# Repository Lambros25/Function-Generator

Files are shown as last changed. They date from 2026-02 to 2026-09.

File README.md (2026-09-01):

# AWG / DDS Function Generator

Laboratory-oriented DDS/AWG signal generator. Current build: v1.2, first revision to
reach full bring-up and characterisation.

## Specs

| | |
|---|---|
| Waveforms | Sine, Square, Sine+Noise, AM, FM |
| Sine range | 0Hz – 1MHz (characterised; DDS/phase-accumulator, <1mHz step) |
| Sine amplitude | ~16Vp-p max at 1kHz (analog pot) |
| Sine flatness | −0.07dB @ 100kHz, −3.1dB @ 1MHz at full drive; flat to −0.09dB @ 1MHz in low-current mode |
| Square range | to at least 2MHz |
| Square edges | ~20ns rise/fall, 10–90% at the BNC |
| Square duty | user-settable 1–99% (default 50%), TC4427-corrected to within ~12ns of target across 1kHz–2MHz |
| Noise | Gaussian-ish, SNR 0–60dB (nominal, not bench-calibrated) |
| AM / FM | depth 0–100% / deviation in Hz |
| Output | BNC, 50Ω series; measured source impedance 53Ω (sine) / 58Ω (square) at 1kHz, Hi-Z loads only |
| DC offset | none observed |
| Resolution | 8-bit R-2R ladder, ~7 effective bits (1% resistor matching) |
| Supply | USB and 2× 9V batteries (measured rails 9.52 / −9.54V) |
| Control | USB CDC serial (plain-text commands) + desktop UI (`scripts/awg_ui.py`) |
| MCU | Raspberry Pi Pico W (RP2040), 225MHz overclocked |

Full measured numbers and the outstanding measurement list: `docs/measurements.md`.
Known limitations and their causes: `docs/limitations.md`.

---

## Structure
- `logs/` — Detailed overview of every work session. (timestamped `.txt`)
- `docs/` — structured technical docs (Markdown)
- `hardware/` — schematics, PCB, BOM, simulations
- `firmware/` — RP2040/Pico firmware
- `scripts/` — helper scripts for committing/pushing logs
- `Push all.bat` / `Push Engineering logs.bat` — Batch files to make git pushing quick and easy.
- `images/` — Images of the project. Used for progress tracking.

### Documentation index (`docs/`)
Start with `design-philosophy.md`, then the version history in `version_requirements.md`,
then `v1_2_architecture.md`.

| File | Contents |
|---|---|
| `design-philosophy.md` | Why this exists and what is out of scope |
| `version_requirements.md` | Version history, requirements and their status |
| `v1_2_architecture.md` | Block diagram, board architecture, open questions |
| `Reconstruction.md` | The sine chain stage by stage, with values |
| `integrated-circuits.md` | Which ICs, in which stages, and why |
| `measurements.md` | Measured performance and what is still uncharacterised |
| `limitations.md` | Known limits, their causes, and mitigations |
| `lessons.md` | Mistakes, what they cost, and the rules derived from them |
| `fabrication.md` | JLCPCB process decisions, DRC, BOM and fee strategy |
| `firmware.md` | Pico W firmware |
| `future-work.md` | Deliberately deferred ideas |
| `overview.md` | Map of the documentation set |

---

## Tooling

- **EDA:** Altium Designer, custom library `lambros25` with LCSC part numbers stored at
  the symbol level so every placement inherits them.
- **Simulation:** LTspice. Behavioural ZOH plus noise source used to model the DAC
  output realistically.
- **Fabrication:** JLCPCB, Economic PCBA tier. Components from LCSC.
- **MCU:** Raspberry Pi Pico W.

Board is 70×70mm, 2-layer FR-4, all-SMD, with a single uninterrupted ground pour on the
bottom layer. Everything is machine-placed except the BNC and the Pico, which are
hand-soldered. `docs/fabrication.md` has the process detail.

---

# Versioning
Integers = major milestones with a defined goal. Decimals = fixes, optimizations, small
additions toward that goal.

| Version | Outcome |
|---|---|
| v0.x | Breadboard. Architecture validated; discrete square path abandoned above ~200kHz. |
| v1.0 | First PCB. Dead on arrival — BOM matcher substituted 2.21Ω for 2.21kΩ across the whole ladder. |
| v1.1 | All-SMD, LC Butterworth introduced. Dead on arrival — LM318 inputs merged onto one net during the KiCad→Altium migration. |
| v1.2 | Working. Current build, characterised. |

Two of three PCB revisions were lost to silent tool-transformation errors rather than
design errors. Both boards looked correct and passed every check that was not a physical
measurement. That is the through-line of this project so far.

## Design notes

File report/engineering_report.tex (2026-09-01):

% =====================================================================
%  AWG / DDS Function Generator — Engineering Process Report
%  Compile: pdflatex (x2, for cross-references and the ToC)
%  Requires: tcolorbox, cleveref, tikz — all standard in TeX Live full
% =====================================================================
\documentclass[11pt,a4paper]{article}

\usepackage[utf8]{inputenc}
\usepackage[T1]{fontenc}
\usepackage{lmodern}
\usepackage{textcomp}
\usepackage[margin=2.4cm]{geometry}
\usepackage{graphicx}
\usepackage{xcolor}
\usepackage{booktabs}
\usepackage{longtable}
\usepackage{array}
\usepackage{tabularx}
\usepackage{colortbl}
\usepackage{microtype}
\usepackage{pdflscape}
\usepackage{enumitem}
\usepackage{titlesec}
\usepackage{fancyhdr}
\usepackage{parskip}
\usepackage{float}
\usepackage{caption}
\usepackage{tikz}
\usepackage[most]{tcolorbox}

% ------------------------------------------------------------ colours
\definecolor{accent}{HTML}{2E4B3F}      % deep green — headings, links
\definecolor{accentline}{HTML}{9DB3A8}  % muted green — rules, ticks
\definecolor{accentpale}{HTML}{EDF2EF}  % wash — table headers, callouts
\definecolor{fail}{HTML}{8C2F1E}        % rust — failures, DOA markers
\definecolor{muted}{HTML}{5F5F5F}       % grey — source citations

% ------------------------------------------------------------ hyperref
\usepackage{hyperref}
\hypersetup{
  colorlinks=true,
  linkcolor=accent,
  citecolor=accent,
  urlcolor=accent,
  linktoc=all,
  bookmarksnumbered=true,
  bookmarksopen=true,
  pdftitle={AWG / DDS Function Generator — Engineering Process Report},
  pdfauthor={Lambros25},
  pdfsubject={Design, failure and bring-up of a laboratory-oriented DDS/AWG signal generator},
  pdfkeywords={AWG, DDS, function generator, R-2R, Butterworth, RP2040, Pico, PCB, Altium, JLCPCB}
}
\usepackage{bookmark}
\usepackage[capitalise,nameinlink]{cleveref}

% ------------------------------------------------------------ macros
\newcommand{\ohm}{\ensuremath{\Omega}}

% Repository links. Set \repobase to your public repo, or comment out the
% linked definitions below and uncomment the plain ones to disable linking.
\newcommand{\doc}[1]{\href{https://github.com/Lambros25/Function-Generator/blob/main/docs/#1}{\texttt{#1}}}
\newcommand{\docu}[2]{\href{https://github.com/Lambros25/Function-Generator/blob/main/docs/#1}{\texttt{#2}}}
\newcommand{\repofile}[1]{\href{https://github.com/Lambros25/Function-Generator/blob/main/#1}{\texttt{#1}}}
% Plain (unlinked) alternatives:
% \renewcommand{\doc}[1]{\texttt{#1}}
% \renewcommand{\docu}[2]{\texttt{#2}}
% \renewcommand{\repofile}[1]{\texttt{#1}}

\newcommand{\srcfile}[1]{\hfill{\footnotesize\color{muted}Source: \texttt{#1}}}

% ------------------------------------------------------------ headings
\titleformat{\section}
{\normalfont\Large\bfseries\color{accent}}{\thesection}{0.8em}{}
[{\color{accentline}\titlerule[0.7pt]}]
\titlespacing*{\section}{0pt}{2.2ex plus 1ex minus .2ex}{1.2ex plus .2ex}

\titleformat{\subsection}
{\normalfont\large\bfseries\color{accent!85!black}}{\thesubsection}{0.7em}{}
\titlespacing*{\subsection}{0pt}{1.8ex plus 1ex minus .2ex}{0.8ex plus .2ex}

% ------------------------------------------------------------ captions
\captionsetup{
  font=small,
  labelfont={bf,color=accent},
  textfont={color=black!80},
  width=0.92\linewidth
}

% ------------------------------------------------------------ headers
\setlength{\headheight}{14pt}
\pagestyle{fancy}
\fancyhf{}
\fancyhead[L]{\small\color{muted} AWG / DDS Function Generator}
\fancyhead[R]{\small\color{muted} Engineering Process Report \quad\textbar\quad \thepage}
\renewcommand{\headrulewidth}{0.4pt}
\renewcommand{\headrule}{\hbox to\headwidth{\color{accentline}\leaders\hrule height \headrulewidth\hfill}}

% ------------------------------------------------------------ lists
\setlist[itemize]{leftmargin=1.3em,itemsep=0.55em,topsep=0.5em}
\setlist[enumerate]{leftmargin=1.6em,itemsep=0.9em,topsep=0.5em}

% ------------------------------------------------------------ callouts
\newtcolorbox{callout}[1][]{
  enhanced, breakable,
  colback=accentpale, colframe=accent,
  boxrule=0pt, leftrule=3pt,
  arc=0pt, outer arc=0pt,
  left=10pt, right=10pt, top=8pt, bottom=8pt,
  fonttitle=\bfseries\color{accent},
  #1}

\newtcolorbox{caveat}[1][]{
  enhanced, breakable,
  colback=fail!4, colframe=fail,
  boxrule=0pt, leftrule=3pt,
  arc=0pt, outer arc=0pt,
  left=10pt, right=10pt, top=8pt, bottom=8pt,
  fonttitle=\bfseries\color{fail},
  #1}

\renewcommand{\arraystretch}{1.25}

\begin{document}

% ================================================================ title
\begin{titlepage}
    \centering
    \vspace*{1.2cm}
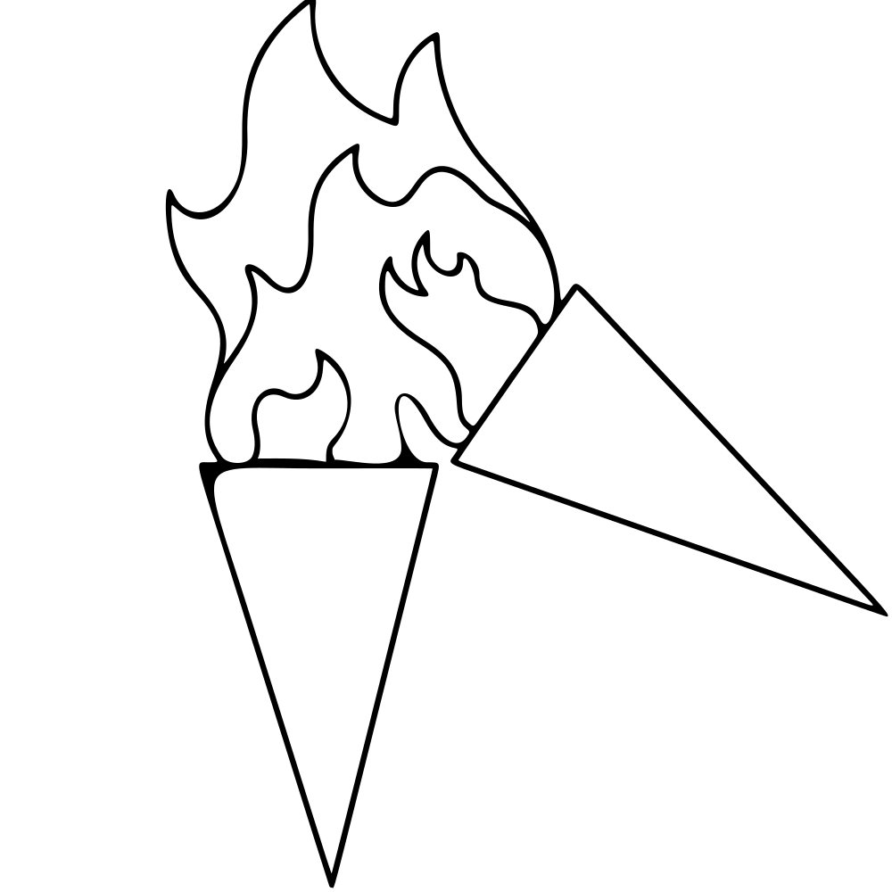
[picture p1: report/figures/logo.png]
    \\[1.4cm]

    {\color{accentline}\rule{0.62\linewidth}{0.8pt}}\\[0.9cm]
    {\Huge\bfseries\color{accent} AWG / DDS Function Generator}\\[0.7cm]
    {\Large Engineering Process Report}\\[0.35cm]
    {\large\itshape How we got here}\\[0.9cm]
    {\color{accentline}\rule{0.62\linewidth}{0.8pt}}\\[1.6cm]

    {\large Current build: \textbf{v1.2} --- working, characterised}\\[0.35cm]
    {\large Three PCB revisions; two arrived dead}\\[2.6cm]

    {\large Lambros25}\\[0.25cm]
    {\small\color{muted} lambros25savva@gmail.com}\\[0.6cm]
    {\small \today}

    \vfill
    {\footnotesize\color{muted}
        Compiled from the timestamped engineering logs, the documentation set, and the
        current state of the repository. Figures and dates are cited to their source
        throughout; see \hyperref[sec:about]{About this report} for what is and isn't
        drawn from the logs.}
\end{titlepage}

\tableofcontents
\clearpage

% ================================================================ summary
\section*{Summary}
\addcontentsline{toc}{section}{Summary}
\label{sec:summary}

\begin{callout}[title={Why? How?}]
    \subsection{Why?}
    This project was aimed to be above all else, a learning experience with a byproduct of a working function generator. It was an excuse
    work with digital analog synthesis, signals, filters, opamps and even switches. A gateway to mixing analog and digital, build intuition
    and experience. Along with that, having a set goal, a tool for proof helped with rough prototyping days, as well as motivation.

    \subsection{How?}
    The idea begun with an arbitrary wave generator. It's in theory, a generator that can output any wave, ideally at any frequency with unlimited power.
    With as a template, after online research the goal of 1MHz was established, using a raspberry pi pico W. The pi pico outputs using an R-2R ladder "steps",
    that is samples of the requested signal, and using the proper filters and reconstruction methods, the full signal is recovered. Ideally the project would
    follow a R-2R -> Reconstruction -> Buffer -> output diagram, which it mostly did with the exception of a variable gain stage, as the pico is limited
    to +3.3Vp-p. Moreover, due to the lack of a proper power supply, it was designed around $2\,x\,9V$ rechargable batteries.

    \subsection{The Arbitrary Wave Generator (AWG)}
    The instrument itself is a laboratory-oriented DDS/AWG signal generator built around an
    R-2R ladder, a 5th-order doubly-terminated LC Butterworth reconstruction filter, and a
    Raspberry Pi Pico W. It uses lm318 at 3 stages, during reconstruction, amplification and buffering, as
    well as an TC4427 for squarewave buffering and an ADG1419 for output selection.
    It produces sine, square, noise, AM and FM under USB control, it is
    characterised from ~DC to 1\,MHz on the sine path and to at least 2\,MHz on the square
    path, and has a known, documented, firmware-mitigated fault in its filter that is
    described here rather than smoothed over.

\end{callout}

% ================================================================ about
\section{About this report}
\label{sec:about}

This is a process report, not a design document. It exists to answer \emph{how did we get
    here}, not to restate what the instrument does --- the documentation set already covers
that, in \doc{design-philosophy.md} for intent, \docu{v1_2_architecture.md}{v1\_2\_architecture.md}
for the current architecture, and \doc{measurements.md} for numbers. This report's job is
the timeline and the honesty around it: what was tried, what worked, what didn't, and
what it cost.

\textbf{Sourcing.} Every dated event below is read from the timestamped engineering logs
(18 files, 27 January -- 1 September 2026) and cross-checked against \doc{lessons.md},
\docu{version_requirements.md}{version\_requirements.md} and \doc{measurements.md} for
figures the logs state only loosely. Where a claim comes from a log entry it is cited by
filename, so it can be checked against the original. A complete index of those files is in
the \hyperref[sec:appendix-sources]{source-material appendix}.

\begin{caveat}[title={One gap in the record}]
    The logs contain no entry at all for v1.1's failure. That account (\cref{sec:v1.1})
    was supplied directly by the author while reviewing this draft rather than found in
    the source material. It is flagged as such where it appears, and in the appendix,
    rather than presented as if it were logged like everything else here.
\end{caveat}

\textbf{What this is not.} It is not a substitute for \doc{lessons.md} --- the rules
derived from failure live there, and this report narrates the failures that produced
them. It is not a spec sheet either; that is the top of \repofile{README.md}.

% ================================================================ glance
\section{Project at a glance}
\label{sec:glance}

\begin{table}[H]
    \centering
    \small
    \begin{tabularx}{0.95\linewidth}{@{}>{\bfseries\color{accent}}l X@{}}
        \toprule
        \rowcolor{accentpale}
        \multicolumn{2}{@{}l}{\textbf{\color{accent}Instrument summary --- v1.2}}                                         \\
        \midrule
        Waveforms        & Sine, square, sine+noise, AM, FM                                                               \\
        Sine range       & 0\,Hz--1\,MHz, characterised; DDS with phase accumulator                                       \\
        Square range     & To at least 2\,MHz                                                                             \\
        Sine amplitude   & $\sim$16\,V\textsubscript{pp} max at 1\,kHz, analog pot                                        \\
        Square edges     & $\sim$20\,ns rise and fall, 10--90\%                                                           \\
        Output impedance & 53\,\ohm\ sine / 58\,\ohm\ square, measured at 1\,kHz                                          \\
        Resolution       & 8-bit R-2R ladder, $\sim$7 effective bits                                                      \\
        Supply           & USB and 2$\times$9\,V batteries                                                                \\
        Control          & USB CDC serial and desktop UI
        (\href{https://github.com/Lambros25/Function-Generator/blob/main/scripts/awg_ui.py}{\texttt{scripts/awg\_ui.py}}) \\
        MCU              & Raspberry Pi Pico W (RP2040), overclocked to 225\,MHz                                          \\
        \bottomrule
    \end{tabularx}
\end{table}

\noindent Full current numbers are in \doc{measurements.md}; the full specification table
is at the top of \repofile{README.md}.

\begin{table}[H]
    \centering
    \small
    \begin{tabularx}{\linewidth}{@{}l X l@{}}
        \toprule
        \rowcolor{accentpale}
        \textbf{\color{accent}Version} & \textbf{\color{accent}What changed}                                  & \textbf{\color{accent}Outcome}                     \\
        \midrule
        v0.x                           & Breadboard. R-2R DAC, discrete and op-amp filtering, discrete square
        path.                          & Architecture validated                                                                                                    \\
        v1.0                           & First PCB. Mixed THT/SMD, 4$\times$ cascaded RC filter.              & \textcolor{fail}{\textbf{Dead on arrival}} --- BOM \\
        v1.1                           & All-SMD, LC Butterworth reconstruction filter.                       & \textcolor{fail}{\textbf{Dead on arrival}} ---
        schematic                                                                                                                                                  \\
        v1.2                           & As v1.1, with the LM318 short fixed and the Pico soldered direct.    & \textcolor{accent}{\textbf{Working}},
        characterised                                                                                                                                              \\
        \bottomrule
    \end{tabularx}
\end{table}

% ---------------------------------------------------------- timeline fig
\begin{figure}[H]
    \centering
    \begin{tikzpicture}[x=1.72cm,y=1cm]
        % baseline
        \draw[line width=1.1pt,accentline] (-0.15,0) -- (8.35,0);
        \foreach \m/\lab in {0/Jan,1/Feb,2/Mar,3/Apr,4/May,5/Jun,6/Jul,7/Aug,8/Sep}{
                \draw[accentline,line width=0.8pt] (\m,-0.1) -- (\m,0.1);
                \node[below=5pt,font=\scriptsize,text=muted] at (\m,-0.1) {\lab};
            }

        % upper tier
        \foreach \x/\txt/\col in {%
        0.87/{Project start}/accent,
        3.65/{Compromise to ICs}/accent,
        6.62/{v1.0 dead on arrival}/fail,
        8.00/{v1.2 working}/accent}{
        \draw[\col!60,line width=0.6pt] (\x,0) -- (\x,1.45);
        \fill[\col] (\x,0) circle (2pt);
        }
        \node[anchor=south,font=\scriptsize\bfseries,text=accent,align=center] at (0.87,1.45) {Project\\start};
        \node[anchor=south,font=\scriptsize\bfseries,text=accent,align=center] at (3.65,1.45) {Compromise\\to ICs};
        \node[anchor=south,font=\scriptsize\bfseries,text=fail,align=center] at (6.62,1.45) {v1.0\\DOA};
        \node[anchor=south east,font=\scriptsize\bfseries,text=accent,align=center] at (8.25,1.45) {v1.2\\working};

        % lower tier
        \foreach \x/\col in {1.96/accent, 6.17/accent, 7.45/fail}{
                \draw[\col!60,line width=0.6pt] (\x,0) -- (\x,0.62);
                \fill[\col] (\x,0) circle (2pt);
            }
        \node[anchor=south,font=\scriptsize,text=accent,align=center] at (1.96,0.62) {first clean\\1\,MHz sine};
        \node[anchor=south,font=\scriptsize,text=accent,align=center] at (6.17,0.62) {v1.0\\ordered};
        \node[anchor=south,font=\scriptsize,text=fail,align=center] at (7.45,0.62) {v1.1\\DOA};

        % spans below
        \draw[line width=3pt,accent!35] (2.02,-0.62) -- (2.92,-0.62);
        \node[below=1pt,font=\scriptsize,text=muted] at (2.47,-0.66) {discrete square detour};
        \draw[line width=3pt,muted!30] (4.02,-0.62) -- (6.0,-0.62);
        \node[below=1pt,font=\scriptsize,text=muted] at (5.0,-0.66) {paused --- exams};
    \end{tikzpicture}
    \caption{Eight months, January to September 2026. Two of the three PCB revisions
        arrived dead; the gap between them is exam season, not debugging.}
    \label{fig:timeline}
\end{figure}

% ================================================================ timeline
\section{Timeline}
\label{sec:timeline}

\subsection{Breadboard era: R-2R, filtering, and a lot of noise}
\label{sec:breadboard}

The project started from nothing on 27 January 2026: Pico toolchain installed, Zadig
drivers for USB, and a first, crude R-2R ladder built from 10\,k\ohm/20\,k\ohm resistors,
driven by AI-generated test firmware for speed. Quality visibly degraded past
60--70\,kHz and the ladder was usable to about 200\,kHz; pushed hard, the bare Pico GPIO
could toggle at up to $\sim$10\,MHz, which set an early --- and, in hindsight,
over-optimistic --- sense of headroom. \srcfile{EngLog 27-01-26 - 0324.txt}

By 18 February the ladder had been changed to 2.2\,k\ohm/1.1\,k\ohm (two 2.2\,k\ohm in
parallel) for better linearity, and serial frequency control was working end to end after
a rewrite of the host I/O code. 1\,MHz looked reachable, by the log's own hedged wording
(``seems that I can manage''), but nothing had been done to condition or verify that
signal yet: the buffer and filter parts it would take to find out were still on the order
list. \srcfile{EngLog 18-02-26 - 1750.txt}

The next entry is the first real filtering attempt: a TL082 unity buffer straight off the
ladder, followed by two RC low-pass stages (470\,\ohm/220\,pF) and a second buffer.
Usable to 100--200\,kHz; at 1\,MHz the signal showed $\sim$50\% amplitude loss, roughly
1\,V of DC offset, and visible jitter and ghosting. Square-wave firmware was added in
parallel but not yet seriously characterised, pending a better op-amp.
\srcfile{EngLog 19-02-26 2036.txt}

\begin{figure}[H]
    \centering
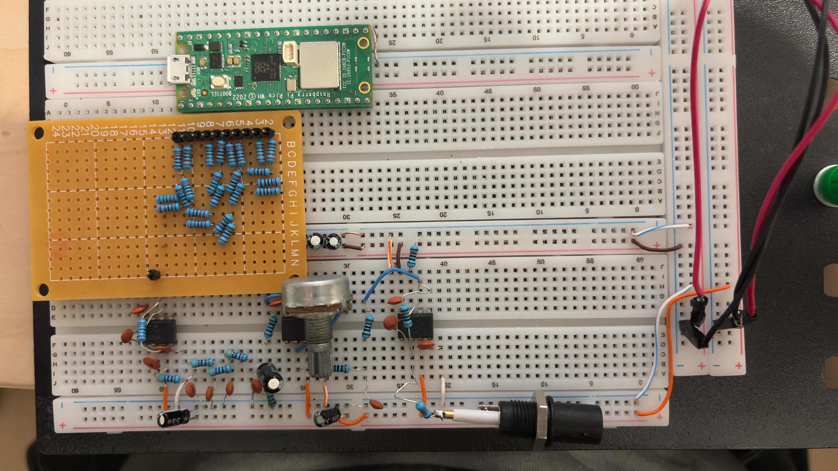
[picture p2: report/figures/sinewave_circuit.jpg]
    
    \caption{Breadboard sine chain during the RC-filter era: R-2R ladder, buffering and
        cascaded filter stages, before the move to LM318 and, later, to a PCB.}
\end{figure}

24 February added a high-pass stage immediately after the ladder to strip the DAC's DC
bias, a 10\,k\ohm potentiometer as a first amplitude control, decoupling
(100\,nF + 10\,\textmu{}F) at the op-amp rails, and the first schematics committed to the
repository. LM318 buffers, solid-core wire and a perfboard were ordered.
\srcfile{EngLog 24-02-26 2100.txt}

\begin{figure}[H]
    \centering
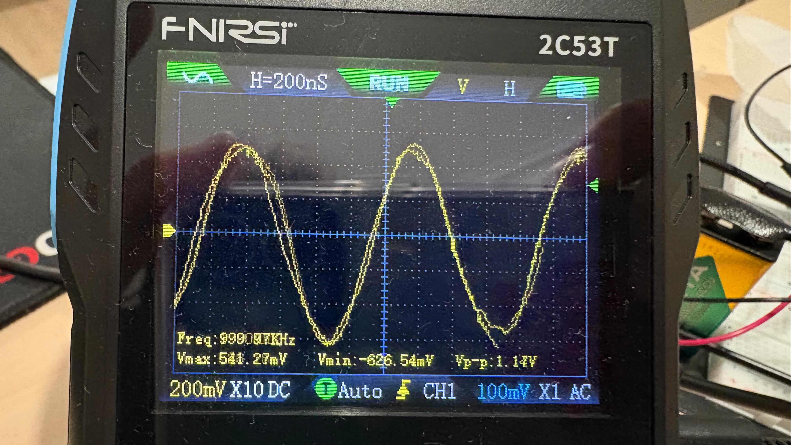
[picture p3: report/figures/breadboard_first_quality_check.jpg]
    
    \caption{First quality check against a bench generator at 1\,MHz, breadboard build.}
\end{figure}

\textbf{The Sallen-Key detour.} With LM318s in hand on 27 February, a full day went into
active Sallen-Key filtering, using parallel resistor and capacitor networks to hit
non-standard ratios. Results were persistently noisy, worse under load, and worse still
through the gain stage. Four candidate causes were ranked in the log itself --- parasitic
capacitance and poor breadboard contact as the top suspect, the unorthodox filter/buffer
layout, bad R-2R contacts newly exposed by the better op-amp, and general wiring and
grounding --- with a closing line that reads, in hindsight, like the project correctly
diagnosing its own next two failure modes:

\begin{quote}
    \itshape ``the brief moments of clean signal with each stage tells me its something
    less\ldots{} systemic.''
\end{quote}
\srcfile{EngLog 27-02-26 0000.txt}

\textbf{First major success.} The very next day, active filtering was abandoned entirely
in favour of five cascaded passive RC stages (four 470\,\ohm/221\,pF low-pass, one
100\,\textmu{}F/1\,M\ohm high-pass), a dedicated inverting gain stage (1\,k\ohm\ input,
0--10\,k\ohm\ feedback pot, 5\,pF compensation) for rail-to-rail swing, a further
low-pass stage to clean up noise the gain stage had uncovered, a voltage-follower output
buffer, and a 47\,\ohm\ series resistor into a BNC connector --- effectively the topology
that would carry through to the PCB. The result was clean, with no ghosting and only a
slight ``vibration'' at 1\,MHz that the log is honest about not being able to attribute to
the circuit rather than the oscilloscope. \srcfile{EngLog 28-02-26 0003.txt}

\begin{figure}[H]
    \centering
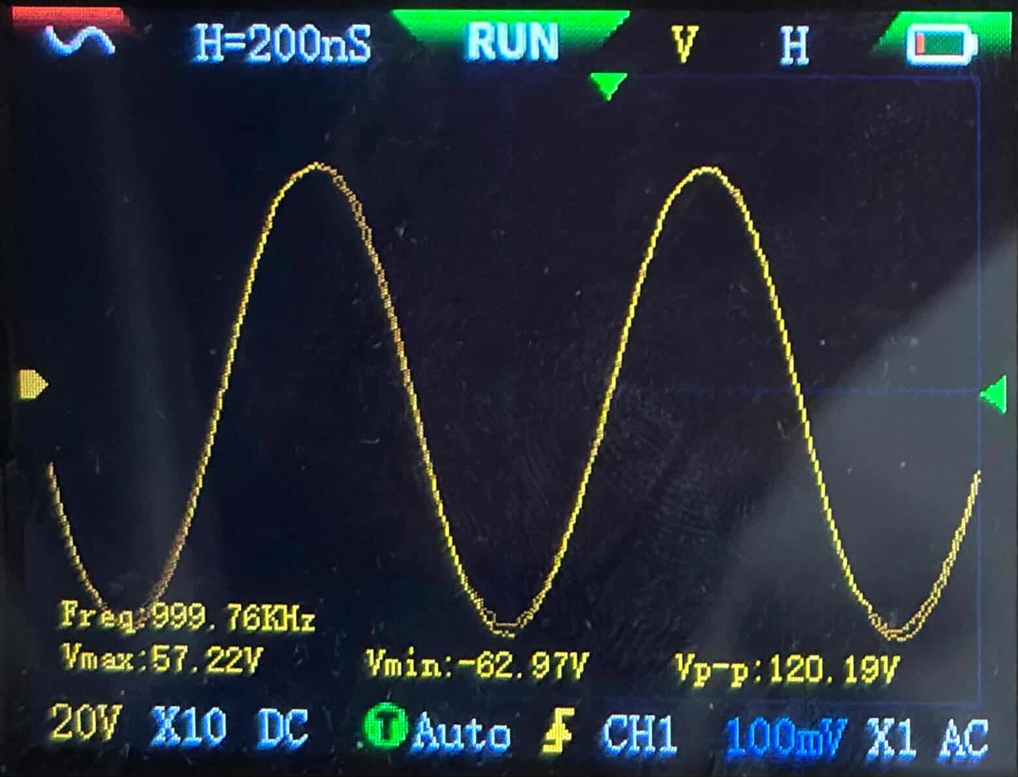
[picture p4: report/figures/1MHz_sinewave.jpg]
    
    \caption{1\,MHz sine capture from the breadboard build, taken around the first
        major success (28 February 2026).}
\end{figure}

\subsection{The discrete square-wave detour}
\label{sec:discrete}

Later the same day, breadboard contact problems fried an LM318 --- a feedback loop opened
under a loose contact. The decision was made to accept the sine chain's Hi-Z-only,
no-current-drive limitations as a deliberate trade for lower parasitics, add square-wave
and arbitrary-waveform output, and move toward a first PCB.
\srcfile{EngLog 28-02-26 1709.txt}

What followed was roughly two weeks of discrete-transistor square-wave buffering, pursued
specifically to build real experience with current amplification rather than reach for an
IC immediately.

\begin{itemize}
    \item \textbf{1 March.} Decision to go discrete; parts ordered.
          \srcfile{EngLog 1-03-26 1637.txt}
    \item \textbf{3 March.} Parts arrive. A hand-derived current amplifier, biased to
          remove the $\sim$0.7\,V junction drop, worked in SPICE but not on the bench. GPIO8 was
          burned by inserting a capacitor believed, incorrectly, to be discharged --- a direct
          hardware casualty rather than a design flaw. \srcfile{EngLog 3-3-26 2336.txt}
    \item \textbf{13 March.} First working square-wave buffer prototype, limited to below
          $\sim$50\,kHz with rounded edges. \srcfile{EngLog 13-03-26 2007.txt}
    \item \textbf{25 March.} An unconventional totem-pole push-pull stage reaches a 1\,MHz
          square wave --- noisy, with a duty-cycle asymmetry the log calls ``duty cycle
          variety'', and limited by a $\sim$1\,k\ohm\ input impedance, visible heating in the
          transistors and resistors, and the battery's own current capacity.
          \srcfile{EngLog 25-03-2026 1739.txt}
    \item \textbf{27 March.} The duty-cycle and frequency-mismatch bugs are traced to the
          first PNP pair's 9\,V rail, and removing it fixes the 1\,MHz case --- but only at high
          frequency; the fix did not carry down to the low-frequency case.
          \srcfile{EngLog 27-03-26 0031.txt}
\end{itemize}

\begin{figure}[H]
    \centering
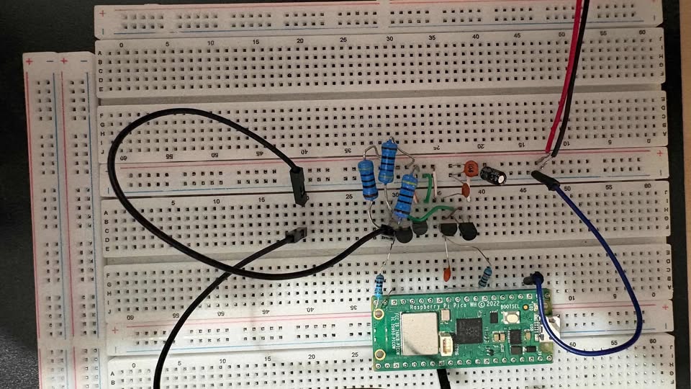
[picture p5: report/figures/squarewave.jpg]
    
    \caption{The discrete-transistor square-wave buffer on breadboard, from this detour
        --- the circuit itself, not a captured output waveform.}
\end{figure}

\subsection{Compromise: ICs, requirements, and a PCB}
\label{sec:compromise}

After the holidays, and after posting for help online without result, the log records a
deliberate compromise: continuing the discrete-transistor path risked never shipping a
working instrument. V1 requirements were fixed --- sine and square from 0 to 1\,MHz at
9\,V peak, digitally adjustable amplitude, PC control via the Pico W, a durable PCB,
strong documentation, BNC output, USB and battery power, and Hi-Z loads only --- and the
square path moved to a TC4427 gate driver, with amplitude control via adjustable LDO rail
limiting (LT3080/LT3090) and a digital pot.

Parts for that scheme were ordered, but neither made it onto the PCB. Simulation showed
the LDO rails degrading the square wave itself, and the digital pot turned out to be
unavailable in the resistance range needed or in a DIP package --- and would have added
noise of its own even if it had been. \srcfile{EngLog 20-04-26 0103.txt}

Project work was then paused through May and into June for exams.
\srcfile{EngLog 01-05-26 1714.txt}

\subsection{v1.0: first PCB, dead on arrival}
\label{sec:v1.0}

The first PCB was designed and ordered as a mixed THT/SMD board --- filtering kept
through-hole for rework access, given how differently breadboard and PCB parasitics were
expected to behave --- using the four-stage cascaded RC filter from the breadboard build.
The rail-limiting amplitude-control scheme from April was tried and dropped: it caused
visible waveform rounding, so amplitude reverted to a simple variable resistor for this
revision. \srcfile{EngLog 6-7-26 1439.txt}

The board arrived, and the failure was immediate and total. The BOM matcher had
substituted 2.21\,\ohm\ resistors for 2.21\,k\ohm\ across the entire R-2R ladder: three
orders of magnitude off, on every rung. This is Lesson~1 in \cref{sec:lessons}.
\srcfile{EngLog 19-07-26 1656.txt}

The same log entry records the immediate pivot: send the board for a respin, replace the
four cascaded RC stages with a 5th-order doubly-terminated LC Butterworth filter
($\sim$1.5\,MHz cutoff, C0G capacitors, 0603 inductors), and move to a fully SMD,
JLCPCB-assembled board. The RC cascade was already a known amplitude bottleneck by this
point --- each stage ate into the signal well before its own corner --- and researching
filter topologies at the time made the Butterworth's flatter passband and steeper rolloff
the obvious replacement, independent of the BOM failure that forced the respin anyway.

\begin{figure}[H]
    \centering
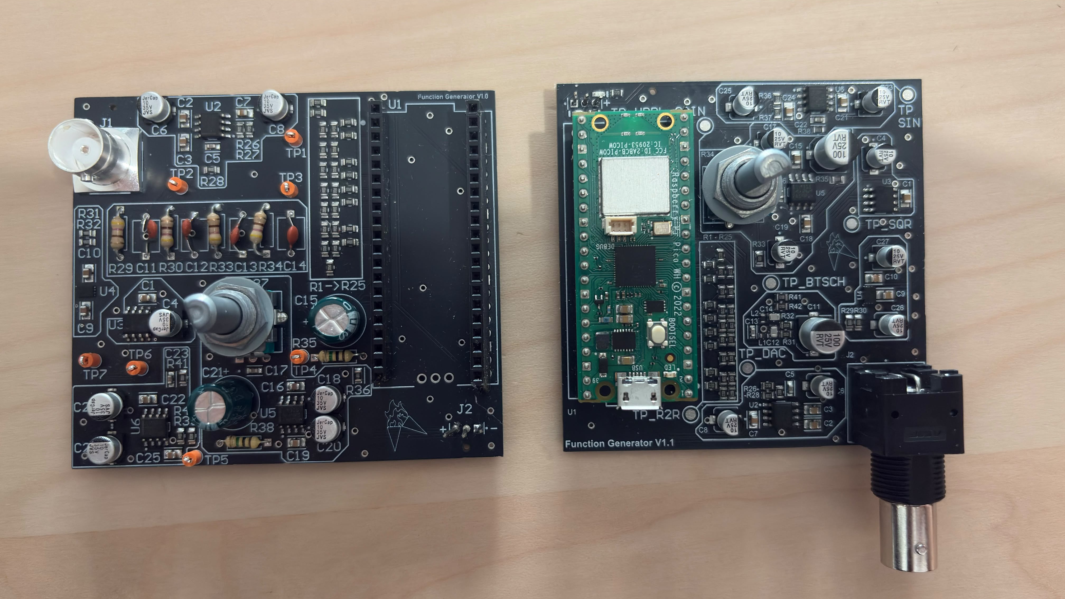
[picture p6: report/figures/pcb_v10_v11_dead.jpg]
    
    \caption{v1.0 (left) and v1.1 (right) side by side --- the two boards that arrived
        dead. v1.0's 2.21\,\ohm\ ladder and cascaded-RC filter section are visible at top
        left; v1.1 already carries the LC Butterworth (L1/L2), the soldered-down Pico and
        the panel-mount BNC that would carry through to v1.2.}
\end{figure}

\subsection{v1.1: Butterworth redesign, dead on arrival}
\label{sec:v1.1}

This version arrived, was soldered up, and went straight to testing --- to no output at
all. The ladder's test point showed nothing and the board was completely silent, with no
immediate way to tell whether the cause was power, firmware or a bad contact.

Pivoting to the square path as a diagnostic step paid off: it worked, and worked well,
with only some edge ringing that turned out to be a probing artefact --- it disappeared
once the scope ground lead was shortened --- rather than a property of the signal. With
sine dead and square clean, the fault was narrowed to the sine chain specifically.

Going over the board repeatedly turned up the cause: a stray trace, left behind during the
KiCad-to-Altium migration, shorting the two inputs of the first-stage LM318. The board's
layout, combined with not having a hot-air rework station on hand, made it impractical to
confirm that this was the \emph{only} fault by reworking and re-testing in place. After
signal insertion at the DAC test point, the rest of the board proved functional at the
lower frequencies the available handheld generator could produce. With the schematic fix
in place, v1.2 was ordered directly.

\begin{caveat}
    No log entry documents this failure or its diagnosis. The account above was supplied
    directly by the author, and \doc{lessons.md}~\#3 is the only other place it is
    summarised.
\end{caveat}

\subsection{v1.2: working build}
\label{sec:v1.2}

With the LM318 short fixed, power LEDs added and costs trimmed in several places, the
board came up clean: tested before assembly, then the Pico soldered directly on. A desktop
host UI was added, along with noise, AM and FM modes on the firmware side. The log calls
the project ``officially completed'' at this point, with bugfixes, additional firmware
features and full characterisation flagged as the next phase rather than as open
requirements. \srcfile{EngLog 01-09026 0306.txt}

\begin{figure}[H]
    \centering
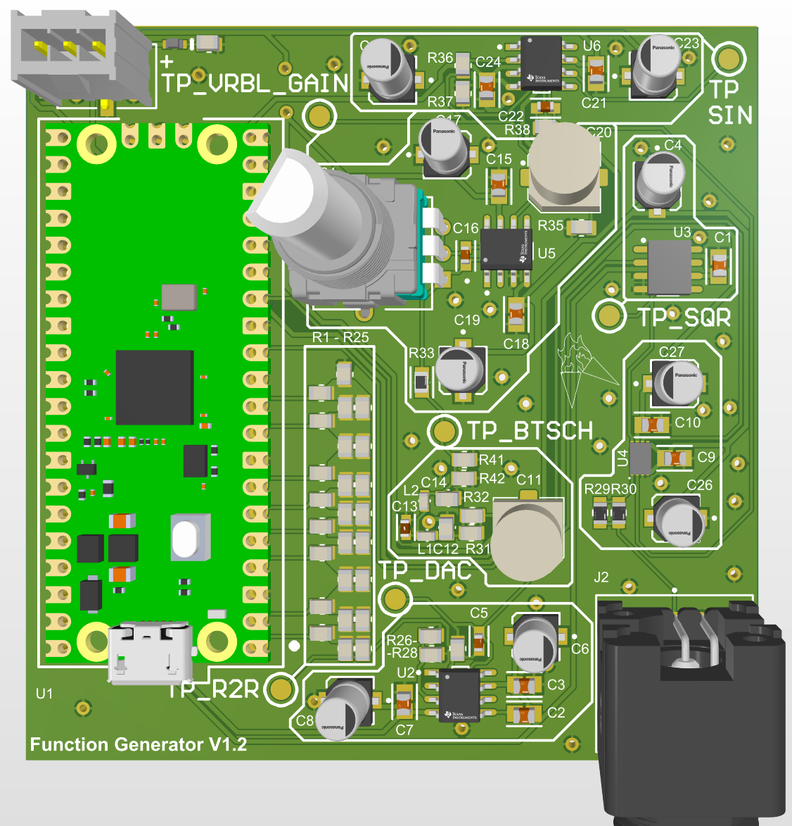
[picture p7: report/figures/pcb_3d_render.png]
    \hfill
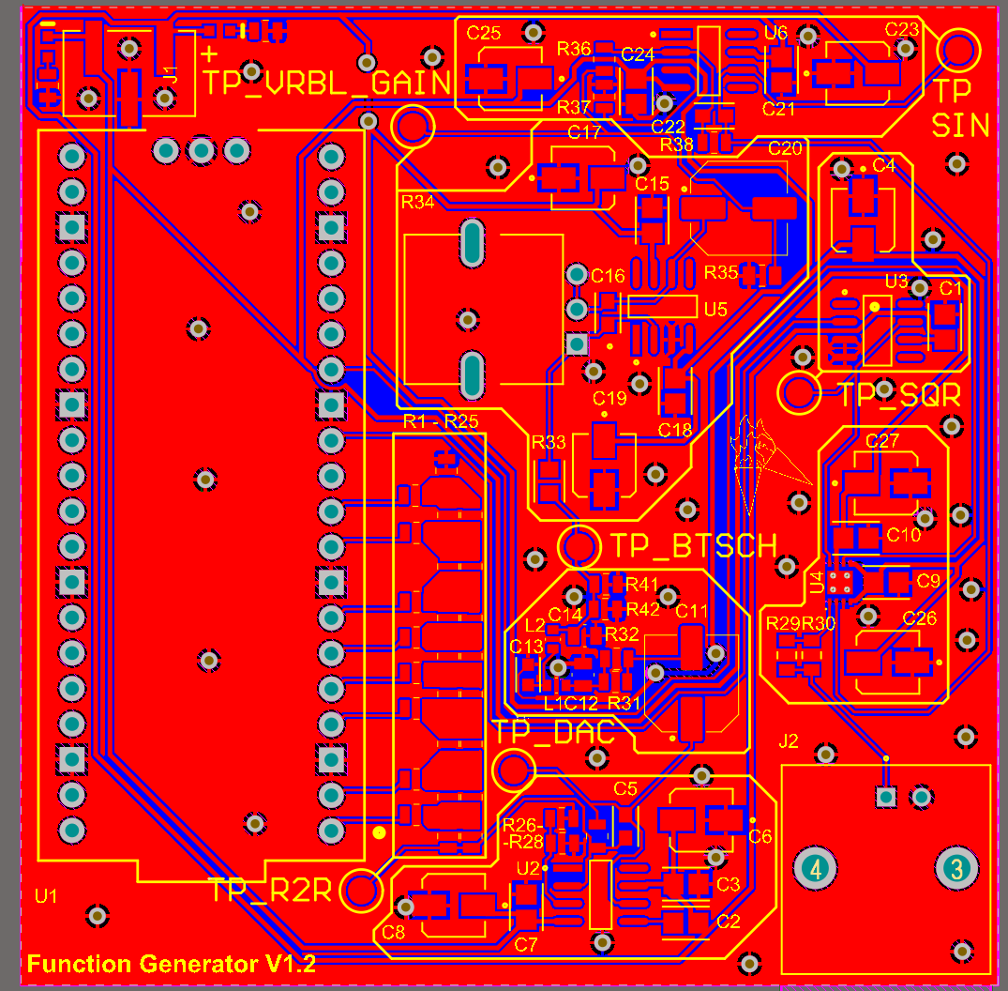
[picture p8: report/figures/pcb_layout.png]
    
    \caption{v1.2 as designed: Altium 3D render and copper layout, August 2026 --- the
        board that was ordered.}
\end{figure}

\begin{figure}[H]
    \centering
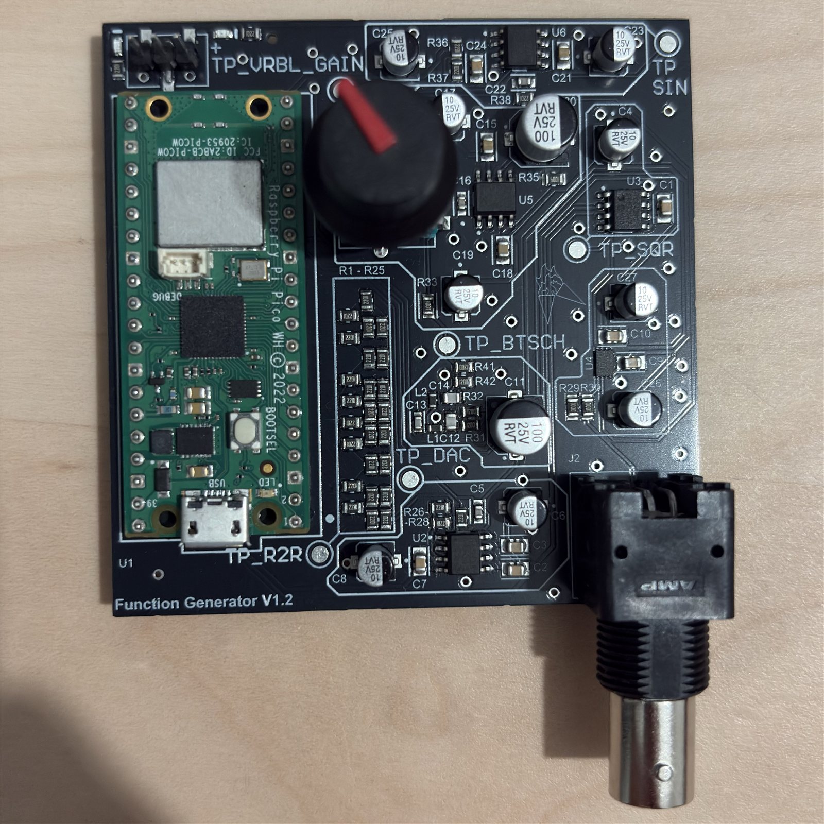
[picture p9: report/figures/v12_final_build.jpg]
    
    \caption{v1.2 as built: the board that arrived, assembled, with the Pico soldered
        directly on and the gain pot and BNC hand-fitted.}
\end{figure}

The very next log entry is where characterisation starts paying off. Full-drive sine
flatness measurements surface a $-3.1$\,dB droop at 1\,MHz, and scaling the DAC lookup
table by four in firmware eliminates it entirely with no hardware change --- which is what
pins the cause on inductor saturation rather than on the filter design or op-amp
bandwidth (Lesson~3, \cref{sec:lessons}). It is diagnosed cleanly and, so far, patched
only in firmware; the real fix is expected to be small, swapping L1/L2 for parts with
adequate saturation current, likely reworkable on the existing board rather than the kind
of fault that forces another respin. A firmware fix for the square wave's duty-cycle
asymmetry is logged in the same entry. \srcfile{EngLog 01-09-2026 1436.txt}

% ================================================================ wrong
\section{What went wrong}
\label{sec:wrong}

\begin{itemize}
    \item \textbf{Every failure that cost a board was invisible to every check that was not
              a physical measurement.} A BOM matcher dropping a unit prefix (Lesson~1), a
          copy-paste merging two nets across an EDA migration (Lesson~2), and a datasheet column
          never read (Lesson~3). None was caught by ERC, DRC, simulation or visual schematic
          review. A fourth, closely related near miss --- name and part-number drift in the
          component library, folded into Lesson~1 alongside the BOM matcher --- was caught early
          enough to cost nothing, which is the only reason it reads as a near miss rather than a
          fourth incident.
    \item \textbf{The Butterworth filter's inductors were selected on inductance, package,
              tolerance and self-resonance --- and not on current rating} (Lesson~3), in a
          60\,\ohm\ system where full-scale drive pushes real current through them. No simulation
          would have surfaced it: LTspice's ideal inductor has no saturation current to violate.
    \item \textbf{Real hardware casualties from real mistakes.} An LM318 fried by a loose
          breadboard contact opening its feedback loop, and GPIO8 burned by inserting a capacitor
          assumed, wrongly, to be discharged (both \cref{sec:discrete}). Both are logged plainly,
          in keeping with this project's own standard for honesty.
    \item \textbf{Two weeks on a discrete square-wave buffer that gave way to an IC anyway.}
          Not a wasted two weeks --- \cref{sec:right} credits the experience --- but the log's own
          tone by late March (``I have realised I grew tired and I'm in way too deep'') is a real
          signal that the discrete-only constraint was fought past the point of being useful, and
          should have been reconsidered sooner.
    \item \textbf{A public request for feedback that produced nothing usable}, noted once
          and not revisited --- worth knowing before trying that channel the same way again.
    \item \textbf{No hot-air rework station on hand when v1.1's LM318 short was found}
          (\cref{sec:v1.1}). With the fault physically identified, the board's layout and the lack
          of that one tool made it impractical to confirm it was the \emph{only} fault by
          reworking in place, so a full respin was ordered on a diagnosis that could not be closed
          out on the bench first.
\end{itemize}

% ================================================================ right
\section{What went right}
\label{sec:right}

\begin{itemize}
    \item \textbf{Killing active filtering when it wasn't working, rather than debugging it
              further.} The Sallen-Key detour (\cref{sec:breadboard}) cost real time, but the decision
          to drop it for passive RC, and later passive LC, rather than chase parasitics in an
          already-suspect breadboard layout, is what produced clean signal the very next day.
    \item \textbf{Diagnosing by changing one variable, twice, at the points that mattered
              most.} The 1\,MHz sine droop was pinned on inductor saturation by scaling the DAC table
          alone and watching the droop disappear with no hardware change (\cref{sec:v1.2}); the
          discrete square buffer's duty and frequency bug was pinned on the first PNP pair's rail by
          removing exactly that (\cref{sec:discrete}). Both are textbook single-variable changes,
          and both are why the causes in this report are stated with confidence rather than hedged.
    \item \textbf{Choosing a passive LC Butterworth over stacking more active stages} once
          the RC cascade's amplitude loss became the limiting factor --- no added op-amp bandwidth
          limit, no added noise, and a much steeper rolloff for the same board complexity.
    \item \textbf{The compromise to use ICs for square-wave buffering.} Two weeks of
          discrete-transistor work (\cref{sec:discrete}) built real understanding of current
          amplification, but the explicit decision to stop and use a TC4427 once shipping was at
          risk is why the project has a working square path at all.
    \item \textbf{Pivoting to the square path as a diagnostic move on v1.1} rather than
          continuing to poke at a completely silent sine chain. A working square output with no
          sine output narrowed the fault to one half of the board immediately, and is what made the
          stray shorted trace findable by review at all (\cref{sec:v1.1}).
    \item \textbf{Soldering the Pico directly to v1.2}, trading reflash convenience --- now
          USB-only --- for the durability a socket does not give a board meant to survive being
          used rather than demonstrated once.
    \item \textbf{Treating ``it compiles clean'' as insufficient evidence.} Both PCB failures
          passed every non-physical check available at the time; the rules derived from them
          (\cref{sec:lessons}) are specifically about closing that gap on the next board, not about
          avoiding the tools that let the errors through.
\end{itemize}

% ================================================================ lessons
\section{Lessons and rules derived}
\label{sec:lessons}

Reproduced from \doc{lessons.md}, which remains the canonical source --- update it there
first if anything here goes stale.

\begin{enumerate}[label=\textbf{\arabic*.},leftmargin=2.1em]
    \item \textbf{BOM and part-identity errors.} Two incidents, same failure class: a part
          gets ordered as something other than what the library says it is, and nothing
          downstream of the library catches it.

          \emph{The 2.21\,\ohm\ incident.} The BOM matcher substituted 2.21\,\ohm\ for
          2.21\,k\ohm\ across the entire R-2R ladder. Cost: one full PCB respin (v1.0).

          \emph{Name and number drift.} Separately, a library entry named as a 0.1\%
          thin-film part carried the LCSC number of a 1\% thick-film part. Harmless in that
          position; the same drift in a precision position would have silently broken the
          design. Caught before it cost anything, which is the only reason it reads as a
          near miss rather than a second respin.
          \begin{itemize}[topsep=0.4em,itemsep=0.35em]
              \item Read the matched part \emph{description} of every BOM line before paying ---
                    value and unit.
              \item Part numbers live at the library level, not per order. The library prevents the
                    error class; the review-page read catches the rest.
              \item Library name, description and LCSC number must agree with each other.
              \item Audit periodically via a parameter-grid view --- inconsistencies are visible in
                    a column that are invisible one component at a time.
              \item Copy the final chosen number back into the library the same day as any
                    order-time substitution.
          \end{itemize}

    \item \textbf{Migration errors.} A KiCad-to-Altium migration merged two LM318 inputs
          onto a single net via a copy-paste that left no visible trace. ERC passed. Cost: one
          full PCB respin (v1.1).
          \begin{itemize}[topsep=0.4em,itemsep=0.35em]
              \item After any cross-EDA paste or import, run ERC \emph{and} a cold continuity check
                    between the input pins of every op-amp instance --- not just the one being worked on.
              \item A schematic that compiles clean is not a schematic that is correct.
          \end{itemize}

    \item \textbf{Maximum current rating.} Butterworth filter inductors were selected on
          inductance, package, tolerance and self-resonance --- not on current rating. Rated
          3\,mA; actual peak current at full scale is $\sim$15\,mA. The saturating ferrite costs
          $-3.1$\,dB at 1\,MHz where the design predicts a flat response.
          \begin{itemize}[topsep=0.4em,itemsep=0.35em]
              \item For series elements in a low-impedance signal path, compute the actual current
                    and check it against the rated and saturation current before selecting --- explicitly,
                    because a 60\,\ohm\ system turns volts into real milliamps in a way that is easy not to
                    think about when reasoning in volts and hertz.
              \item Simulation will not catch this: LTspice inductors are ideal and
                    current-independent.
              \item Hotfix: the firmware low-current mode (lookup table $\div4$) restores linearity
                    at the cost of amplitude and two bits of resolution --- diagnostic-grade, not a fix.
              \item Real fix: the same inductance in a larger package with adequate saturation
                    current.
          \end{itemize}
\end{enumerate}

% ================================================================ current
\section{Current state --- v1.2}
\label{sec:current}

Full numbers live in \doc{measurements.md} and at the top of \repofile{README.md}; this
section is the short version, current as of this report.

\textbf{Working.} Sine from 0\,Hz to 1\,MHz, DDS with a phase accumulator. Square to at
least 2\,MHz, PIO-generated, with user-settable duty and a TC4427-asymmetry correction.
Sine+noise (SNR 0--60\,dB, nominal), AM (0--100\% depth) and FM (deviation in Hz). USB CDC
serial control with a plain-text command protocol and a desktop UI. No DC offset observed.
Output impedance measured rather than assumed: 53\,\ohm\ sine, 58\,\ohm\ square.

\textbf{Known limitations.} Full detail and causes are in \doc{limitations.md}. In short:
the filter inductors are under-rated for the current they actually carry (Lesson~3, with a
firmware workaround rather than a fix); the filter corner sits at $\sim$1.0\,MHz against a
1.5\,MHz simulation and this is still unexplained; the 9\,V-peak output requirement is not
met on $\pm$9.5\,V rails; the instrument drives Hi-Z loads only, with no output buffer
after the switch; amplitude control is an analog pot rather than digital; and THD and
jitter are uncharacterised for lack of equipment.

% ================================================================ open
\section{Open items and future work}
\label{sec:open}

Drawn from \docu{version_requirements.md}{version\_requirements.md} and
\doc{future-work.md}.

\begin{itemize}
    \item \textbf{Digital amplitude control} --- firmware lookup-table scaling, possibly with
          coarse analog gain switching. High priority in \doc{future-work.md}.
    \item \textbf{Noise, AM and FM are implemented and running} but still listed as a future
          requirement, and their key parameters (noise-mode SNR, AM depth) are calculated rather
          than bench-calibrated. Both should be resolved together rather than documented as two
          separate gaps.
    \item \textbf{The DDS paths accept commanded frequencies well past their
              $\sim$2.017\,MHz Nyquist limit with no check}, and alias silently rather than clamp or
          error. This is exactly the mechanism behind the earlier ``2\,MHz sine'' reading that
          turned out to be an alias.
    \item \textbf{Square duty and its correction toggle have no control in the host UI} ---
          serial-only for now.
    \item \textbf{Output impedance is measured on one unit only}; board-to-board variation is
          untested.
    \item \textbf{Deliberately deferred:} higher-voltage output, selectable output impedance,
          output protection, an onboard display, standalone operation and self-calibration all
          remain in \doc{future-work.md}.
\end{itemize}

% ================================================================ appendix
\clearpage
\section*{Appendix A: source material}
\addcontentsline{toc}{section}{Appendix A: source material}
\label{sec:appendix-sources}

\begin{longtable}{@{}ll@{}}
    \toprule
    \rowcolor{accentpale}
    \textbf{\color{accent}Log file}      & \textbf{\color{accent}Covers}                \\
    \midrule
    \endfirsthead
    \toprule
    \rowcolor{accentpale}
    \textbf{\color{accent}Log file}      & \textbf{\color{accent}Covers}                \\
    \midrule
    \endhead
    \texttt{EngLog 27-01-26 - 0324.txt}  & Project start; first R-2R ladder             \\
    \texttt{EngLog 18-02-26 - 1750.txt}  & Serial I/O working; ladder resistor change   \\
    \texttt{EngLog 19-02-26 2036.txt}    & TL082 buffer and filter; square wave added   \\
    \texttt{EngLog 24-02-26 2100.txt}    & HPF, pot, decoupling; schematics started     \\
    \texttt{EngLog 27-02-26 0000.txt}    & Sallen-Key detour; noise-cause ranking       \\
    \texttt{EngLog 28-02-26 0003.txt}    & Passive filter redesign; first major success \\
    \texttt{EngLog 28-02-26 1709.txt}    & LM318 fried; decision to move to PCB         \\
    \texttt{EngLog 1-03-26 1637.txt}     & Decision to go discrete for square wave      \\
    \texttt{EngLog 3-3-26 2336.txt}      & Parts arrive; GPIO8 burned                   \\
    \texttt{EngLog 13-03-26 2007.txt}    & First discrete square buffer ($<$50\,kHz)    \\
    \texttt{EngLog 25-03-2026 1739.txt}  & 1\,MHz totem-pole square prototype           \\
    \texttt{EngLog 27-03-26 0031.txt}    & Duty-cycle and frequency bug fixed           \\
    \texttt{EngLog 20-04-26 0103.txt}    & Compromise to ICs; V1 requirements set       \\
    \texttt{EngLog 01-05-26 1714.txt}    & Project paused for exams                     \\
    \texttt{EngLog 6-7-26 1439.txt}      & v1.0 PCB ordered                             \\
    \texttt{EngLog 19-07-26 1656.txt}    & v1.0 DOA (2.21\,\ohm); v1.1 re-order decided \\
    \emph{(author account, no log file)} & v1.1 DOA; LM318 short found and diagnosed    \\
    \texttt{EngLog 01-09026 0306.txt}    & v1.2 complete; UI, noise, AM, FM added       \\
    \texttt{EngLog 01-09-2026 1436.txt}  & Inductor saturation found; duty cycle fixed  \\
    \bottomrule
\end{longtable}

\begin{caveat}[title={Note on that one row}]
    No log entry documents v1.1's own failure or its diagnosis. That account
    (\cref{sec:v1.1}) was supplied directly by the author, and \doc{lessons.md}~\#3 is the
    only other place it is summarised.
\end{caveat}

% ================================================================ schematic
\clearpage
\section*{Appendix B: current schematic (v1.2)}
\addcontentsline{toc}{section}{Appendix B: current schematic (v1.2)}
Dated 26 August 2026, reproduced at full page width overleaf. The embed is vector ---
scroll or pinch-zoom reads every net and value losslessly --- and the schematic is
also a link: click it to open
\href{https://github.com/Lambros25/Function-Generator/blob/main/hardware/schematic_overview.pdf}{\texttt{hardware/schematic\_overview.pdf}}
on GitHub, a
real URL that works from anywhere this PDF is opened, phone included, unlike a
relative path into a folder that may not travel with the file.

\begin{landscape}
    \begin{figure}[H]
        \centering
        \href{https://github.com/Lambros25/Function-Generator/blob/main/hardware/schematic_overview.pdf}{%
            }
    \end{figure}
\end{landscape}

\end{document}

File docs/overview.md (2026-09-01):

# The Project

## Description
The final goal of this project is to build a laboratory-grade AWG that satisfies
my needs and ambitions. The emphasis is not only on the final instrument, but on
the learning process itself — understanding signal generation, signal integrity,
and real engineering trade-offs.  
This is why the device is built rather than bought.

---

# Documentation Overview

This folder contains the structured technical documentation of the project.
Each file has a specific role.

- `v1_2_architecture.md`  
  Overview of the architecture of the system. Goals currently being worked on as well
  as the next steps, and open questions the measurements have not closed.

- `design-philosophy.md`  
  Window into the philosophy and the reason for the construction of this project.

- `fabrication.md`  
  PCB fabrication and assembly knowledge: JLCPCB process decisions, DRC
  calibration, BOM/fee strategy, ordering workflow.

- `firmware.md`  
  Pico W firmware: signal generation, host interface, features — read off `AWG.c`
  directly, including the pin map, command reference, and known gaps.

- `future-work.md`  
  Outlines medium- and long-term ideas that are intentionally deferred.

- `integrated-circuits.md`  
  Tracks which ICs are currently in use, in which stages and why.

- `lessons.md`  
  Mistakes made, what they cost, and the rules derived from them.

- `limitations.md`  
  Lists known hardware and software limitations, their causes, and potential
  mitigation strategies.

- `measurements.md`  
  Measured performance of the current build, and what remains uncharacterised.

- `overview.md`  
  The current file, meant to give a coherent overview of the documentation.

- `Reconstruction.md`  
  Details on the reconstruction process, stage by stage.

- `version_requirements.md`  
  Version history, current and past project goals, performance targets and scope.
  Requirements are updated as milestones are achieved.

---

## Where to start
Read `design-philosophy.md`, then the version history at the top of
`version_requirements.md`, then `v1_2_architecture.md`. `lessons.md` is the honest
part.

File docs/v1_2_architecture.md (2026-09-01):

# Architecture

## Block Diagram (current)
```
[PC UI] -> [USB Protocol] -> [Raspberry Pi Pico W]
    |
    +-- sine:   [R-2R] -> [LM318 Buffer] -> [LC Butterworth Filter] -> [AC Coupling]
    |                  -> [Variable Gain (LM318 + pot)] --+
    |                                                     |
    +-- square: [TC4427 Buffer] --------------------------+
                                                          |
                              [ADG1419 Switch] -> [50Ω series] -> [BNC]
```

Two things follow from this and are worth stating explicitly:

- **The square path contains no op-amp.** Pico GPIO -> TC4427 -> switch. Confirmed by
  measurement: 20ns edges on a ~10.8V swing are ~430V/µs, far beyond LM318 slew rate.
- **There is no output buffer after the switch.** The gain stage drives the ADG1419
  directly on the sine side, and the 50Ω series resistance sits between the switch and
  the BNC — that resistor is the same physical component for both modes, but total
  source impedance is not identical between them: measured 53Ω (sine) vs. 58Ω (square)
  at 1kHz (`measurements.md`). Sine's +3Ω over nominal is the ADG1419's Ron; square's
  extra ~5Ω on top of that is the TC4427's own output resistance, which sits in the
  square path only (no op-amp there to absorb it).

## Goals (v1.x)
- PC UI control (USB)
- Variable gain sinewave, squarewave.
- Frequency range: 0Hz-1MHz.
- 50Ω source impedance, intended for Hi-Z loads.

## Notes
- Define "clean" using measurable specs (THD, jitter, amplitude flatness, spurs).

## Consequences of dropping the output buffer
- With no buffer after the switch, the gain-stage LM318 is the only thing driving the
  output network. Into Hi-Z that is trivial. Into a 50Ω terminated load it is not:
  16Vp-p across the 50Ω series plus a 50Ω termination asks for ~80mA, well beyond the
  LM318's ~±20mA output. Hi-Z loads are the stated intent, but this should be written
  down as a hard constraint rather than a preference.
- The ADG1419's Ron (~2.1Ω) is in series with the 50Ω and adds to source impedance in
  both modes; the square path additionally carries the TC4427's output resistance.
  Measured: 53Ω sine, 58Ω square (see above and `measurements.md`).

## Open questions
- Filter corner measures ~1.0MHz against a simulated 1.5MHz; unexplained.
  See Reconstruction.md.

## Hardware Architecture (v1.2 PCB)
    Breadboard and early planning used a modular validation approach
    (separate DAC / filter / output stages, accessible for rework).

    The v1.2 PCB consolidates all stages onto a single 70x70mm 2-layer
    all-SMD board, JLCPCB-assembled. This is the "consolidation" step the
    modular philosophy was building toward.

    Assembly: everything is SMD and machine-placed except the BNC connector and the
    Pico, both hand-soldered. The Pico is soldered directly to the board on v1.2 —
    no socket, so it is not removable.

    Rework access is preserved via:
        - Test points / bare pads on stage boundaries and supply rails

    Ground strategy: single uninterrupted GND pour on the bottom layer,
    VEE island under the ADG1419, stitching vias around the op-amps.

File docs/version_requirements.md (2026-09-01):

# Versioning
Integers = major milestones with a defined goal. Decimals = fixes, optimizations,
small additions toward that goal.

---

# Version History

## v0.x — Breadboard prototype
    - Pico-driven R-2R ladder, discrete square-wave path, cascaded RC reconstruction.
    - Found that a discrete square path could not be kept clean past ~200kHz.
      This is what led to the TC4427 driver.
    - Parasitics and noise accepted deliberately in exchange for iteration speed.
    - Outcome: architecture validated, moved to PCB.

## v1.0 — First PCB order
    - Mixed THT/SMD. LM318 and filter passives kept through-hole for rework.
    - Reconstruction: 4x cascaded RC low-pass.
    - Outcome: DEAD ON ARRIVAL. The BOM matcher substituted 2.21Ω for 2.21kΩ across
      every R-2R position. Failure found on delivery. See lessons.md #1.

## v1.1 — Second PCB order
    - Fully all-SMD, JLCPCB-assembled.
    - Reconstruction filter replaced: 4x cascaded RC -> 5th-order doubly-terminated
      LC Butterworth (flat passband, see Reconstruction.md).
    - Test points reduced to bare pads to cut cost.
    - BOM corrected after the 2.21Ω incident.
    - Outcome: DEAD ON ARRIVAL. LM318 inputs (pins 2/3) were merged onto a single net
      during the KiCad -> Altium migration. See lessons.md #3.

## v1.2 — Third PCB order (current build)
    - LM318 input short fixed.
    - Pico soldered directly to the board.
    - First revision to reach full bring-up and characterisation. See measurements.md.
    - Outcome: WORKING. Known open issue: filter inductors under-rated for the
      current actually flowing through them (lessons.md #4).

Two of three PCB revisions were lost to silent tool-transformation errors rather than
design errors. Both boards looked correct and passed every check that was not a
physical measurement.

---

# V1.x Requirements — status

- Sine and Square output 0-1MHz
    PARTIAL. Sine is characterised to 1MHz; the usable upper limit above 1MHz has not
    been established. Square confirmed to 2MHz.

- 9V peak output
    NOT MET. Max sine is ~16Vp-p (8V peak) at 1kHz, falling to ~7Vp-p at 1MHz with the
    pot fixed for 10Vp-p. On ±9.5V rails an LM318 cannot reach 9V peak. Either the
    requirement moves to ±15V rails (see the bench PSU project) or the spec is restated.

- Sine adjustable amplitude
    MET via analog pot. Digital amplitude control still deferred.

- PC controlled via Pico W through simple UI
    MET. Firmware is undocumented — see firmware.md.

- PCB for durability and cleanliness
    MET.

- Strong documentation and reproducibility
    IN PROGRESS.

- BNC output, 50Ω source impedance, Hi-Z loads
    MET, with the actual figure now measured rather than assumed: 53Ω sine / 58Ω square
    at 1kHz into 100Ω (`measurements.md`), on top of the shared 50Ω series resistor after
    the ADG1419 — sine's excess is the switch's Ron, square's larger excess also carries
    the TC4427's output resistance. Hi-Z is a hard constraint — with no output buffer
    the gain stage cannot drive a 50Ω terminated load at full amplitude.

- USB & battery powered
    MET. Characterised on 2x 9V batteries (rails 9.52 / -9.54V).

---

# Future Versions

- PC-controlled user interface (visual, intuitive, USB-based)
  UI must include self-assessment / signal-quality reporting:
  - Display measured or estimated jitter, THD/THD+N, amplitude error, spurs
  - Provide a clear "heads-up" to the user about signal cleanness and limitations

- Digital amplitude control (firmware R-2R lookup-table scaling,
  potentially with coarse analog gain switching)

- DDS / AWG waveform generation
    - Standard waveforms + arbitrary waveforms
    - Modulated signals (AM, FM, PM, PWM; later digital modulation)
    - Emphasis on clean signal characteristics:
        - Jitter / phase noise
        - THD / distortion
        - Amplitude accuracy & flatness
        - Spur suppression

- Robust output stage:
  - High-voltage capability (≈40-50 Vpp at low frequency)
  - Proper buffering & impedance

- Protection:
  - Short-circuit
  - Overvoltage / back-drive protection
  - ESD

- Discrete components

- Variable squarewave gain

### Non-requirements
    - Commercial certification

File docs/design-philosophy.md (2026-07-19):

# Project Scope
    Aim to design, develop and build a laboratory-grade arbitrary waveform generator as an education and engineering exercise.

## Goals
    - `Measurement-grade performance`
    - `Engineering rigor and documentation`
    - `Iterative Validation`
    - `Robustness and repeatability`

Commercial constraints (cost optimization, enclosure design, regulatory certification) are out of scope.

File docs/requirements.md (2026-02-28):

# Initial Long Term Requirements 10/01/2026

- PC-controlled user interface (visual, intuitive, USB-based)
UI must include self-assessment / signal-quality reporting:
  - Display measured or estimated jitter, THD/THD+N, amplitude error, spurs
  - Provide a clear “heads-up” to the user about signal cleanness and limitations

- DDS / AWG waveform generation
    - Standard waveforms + arbitrary waveforms
    - Modulated signals (AM, FM, PM, PWM; later digital modulation)
    - Phased frequency targets:
        - Start low (≤100 kHz)
        - Extend to MHz range
        - High-frequency/RF as a long-term goal
    - Emphasis on clean signal characteristics:
        - Jitter / phase noise
        - THD / distortion
        - Amplitude accuracy & flatness
        - Spur suppression

- Robust output stage:
  - Start at 18Vpp
  - Later high-voltage capability (≈40–50 Vpp at low frequency)
  - Proper buffering & impedance

- Protection:
  - ESD
  - Short-circuit
  - Overvoltage / back-drive protection
- Strong documentation and reproducibility

### Non-requirements
    - Commercial certification

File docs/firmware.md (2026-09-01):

# Firmware

Raspberry Pi Pico W. Everything the instrument does that isn't a resistor is here: the
sine is a lookup table clocked into an R-2R ladder, the square is a PIO-generated GPIO
toggle, and the host UI is the only user interface.

This document is a description of `firmware/AWG/AWG.c`, not a design intent — every
figure below is read off the code or the build files, not assumed. Re-verify it after
any firmware change; a stale firmware.md is worse than none.

---

## Target and toolchain
- Raspberry Pi Pico W (RP2040), soldered directly to the v1.2 board — not socketed, so
  reflashing is over USB only.
- Language/SDK: C (C11), built against the **Raspberry Pi Pico SDK 2.2.0** via CMake
  (`firmware/AWG/CMakeLists.txt`). Not MicroPython — `project(AWG C CXX ASM)` links
  `pico_stdlib`, `pico_multicore`, and the `hardware_pio`/`hardware_clocks` etc. SDK
  libraries directly. `hardware_spi`, `hardware_i2c`, `hardware_dma`, `hardware_interp`,
  `hardware_timer` and `hardware_watchdog` are linked but unused by `AWG.c` as it stands
  — worth pruning if the build is ever slimmed down.
- Developed in VS Code. A standalone host application instead of running from the editor
  is listed under `future-work.md`.
- **Build and flash procedure** (as actually run to build/flash this firmware):
  1. Toolchain lives under `~/.pico-sdk/` (installed by the Pico VS Code extension):
     SDK 2.2.0, ARM toolchain `14_2_Rel1`, CMake `v3.31.5`, Ninja `v1.12.1`, picotool
     `2.2.0-a4`. `firmware/AWG/.vscode/settings.json` has the exact paths.
  2. Set `PICO_SDK_PATH` / `PICO_TOOLCHAIN_PATH` and prepend the toolchain/cmake/ninja/
     picotool `bin` dirs to `PATH`, then run `ninja -C firmware/AWG/build` (the CMake
     configure step has already been run once into `firmware/AWG/build/`; re-run
     `cmake -G Ninja ..` there if `CMakeLists.txt` changes). Output: `AWG.uf2` in that
     `build/` directory.
  3. Flash: put the Pico in BOOTSEL mode — either hold BOOTSEL while plugging in USB, or,
     if it's already running firmware with USB CDC enabled, force it with
     `picotool reboot -f -u`. It re-enumerates as a `RPI-RP2` USB mass-storage drive;
     copy `AWG.uf2` onto it. The Pico reboots into the new firmware automatically and the
     drive disappears — that disappearance is the confirmation the flash took.

## Pin map
All of it is `#define`d at the top of `AWG.c`; nothing else in this firmware drives a
GPIO.

| Signal | GPIO(s) | Notes |
|---|---|---|
| R-2R ladder (sine DAC) | GPIO0–GPIO7 | `DAC_PINS_BASE = 0`, 8 consecutive pins, driven by PIO0 SM0. Bit order: `generate_sine_table()`/`generate_raw_sine_table()`/`recompute_noise_params()` write each sample through `reverse_bits()` before it reaches the FIFO, and the PIO's `out pins, 8` (`sm_config_set_out_shift(shift_right=true, threshold=8)`) then places OSR bit *i* on GPIO*i* unshifted (a single 8-bit `out` moves the whole OSR at once, so shift direction doesn't reorder it). Net effect: **GPIO0 = MSB, GPIO7 = LSB** of the logical sample value. This is derived from the code, not cross-checked against the Altium net names — but the sine output measures correctly (`measurements.md`), so the code/hardware pairing is self-consistent in practice. |
| Square wave out | GPIO9 | `SQUARE_OUT_PIN`. PIO0 SM1, into the TC4427. |
| ADG1419 select | GPIO10 | `ADG_SELECT_PIN`. Logic level 1 routes SQUARE, 0 routes SINE (`ADG_SQUARE_LEVEL = 1`). |
| LEDs / test outputs | none | No other GPIO is touched by this firmware. |
| UART | none | `pico_enable_stdio_uart(AWG 0)` — UART stdio is disabled; host comms are USB CDC only. |

---

## Sine generation

The ladder is fed from a precomputed lookup table. Output frequency is set by how fast
the table is clocked out, not by the table contents.

- **Table depth / width:** `SINE_TABLE_SIZE = 256` samples per cycle. There are three
  separate 256-entry, 8-bit tables, all regenerated together whenever amplitude mode or
  SNR changes: `sine_table` (unsigned, bit-reversed, feeds the DAC directly in SINE/NOISE
  mode), `raw_sine_table` (signed, `~sin*128`, feeds the AM/FM math), and
  `noise_sine_table` (signed, scaled to the SNR-derived amplitude, feeds NOISE mode).
- **Timing mechanism: PIO, CPU-fed — not DMA, not a timer ISR.** `dac_program` is a
  1-instruction PIO0 SM0 program (`out pins, 8`) clocked by a fractional divider set from
  `clock_get_hz(clk_sys) / SAMPLE_RATE_HZ`, so the PIO alone sets the sample *rate*.
  core1 is the one pushing sample *values*: a tight loop calls `pio_sm_put_blocking()`
  once per sample (32 per outer iteration), which blocks on the PIO's TX FIFO and so
  paces core1 to the DAC's actual output rate. `hardware_dma` is linked in
  `CMakeLists.txt` but no DMA channel is used anywhere in `AWG.c` — dead link, not a
  hidden data path.
- **Maximum update rate achieved:** `SAMPLE_RATE_HZ = 4034843` (~4.03MS/s), fixed at
  compile time, shared by SINE/NOISE/AM/FM (SQUARE has its own independent PIO SM and no
  such fixed rate — see below). At 1MHz output that is **4034843 / 1000000 ≈ 4.03
  samples/cycle** — genuinely few, and a real, separate contributor to any droop at the
  top of the sine range, on top of the inductor saturation in `lessons.md` #4. It also
  fixes the DDS's Nyquist limit at `SAMPLE_RATE_HZ / 2 ≈ 2.017MHz`: any commanded
  frequency above that aliases rather than attenuates. This is exactly the mechanism
  behind `measurements.md`'s open item "the earlier '2MHz sine' reading was an alias."
- **Frequency resolution: phase-accumulator, i.e. this genuinely is a DDS,** not a
  fixed-table player or an integer-divider scheme — for SINE/NOISE/AM/FM.
  `sine_phase_increment = (freq_hz * 2^32) / (SAMPLE_RATE_HZ * calibration_factor)` is a
  32-bit accumulator advanced every sample; the table index is its top 8 bits. Step size
  is `SAMPLE_RATE_HZ / 2^32 ≈ 9.39e-4 Hz` (<1mHz) — far below any other error source, so
  effectively continuous. **SQUARE is different and NOT phase-accumulator based** — see
  "Square generation" below; it has its own, much coarser, frequency quantization.
- The command validator (`f<number>`) accepts up to 50,000,000 Hz for *every* waveform,
  including the DDS ones, with no Nyquist check. Commanding a SINE/NOISE/AM/FM frequency
  above ~2.017MHz will alias silently rather than error or clamp — worth fixing, not
  fixed here since it's outside this pass's scope.

### Effective resolution
The ladder is ~7 effective bits worst-case, limited by 1% resistor matching rather than
by firmware (`limitations.md`). Firmware cannot recover this; only 0.1% thin-film parts
can.

---

## Low-current mode

A runtime-toggleable mode that scales every sine-derived table (`sine_table`,
`raw_sine_table`, `noise_sine_table` — so SINE, NOISE, AM and FM all share it; SQUARE is
unaffected) to 1/4 amplitude before output.

- Purpose: peak current through the filter inductors drops from ~15mA to ~3.75mA,
  bringing the ferrite out of saturation. Measured effect is decisive — the −3.1dB droop
  at 1MHz disappears entirely and the passband goes flat to −0.09dB, with no hardware
  change. This is the experiment that identified the fault.
- Cost: 4× less output amplitude, and two bits of an already ~7-bit-effective ladder,
  leaving ~5 effective bits.
- **Status: this is no longer purely a one-off diagnostic.** It started as a compile-time
  hack used once to isolate the saturation fault; it is now a `volatile` runtime state
  (`low_amplitude_mode`, regenerated live via `amplitude_mode_changed`), toggleable at any
  time over serial (`amp<0/1>`) or from the host UI's `<3mA` button — a standing,
  user-facing low-current output option, not just a debug-only measurement. The fix for
  the underlying saturation is still a higher-saturation-current inductor; this mode
  works around it rather than fixing it.
- **Naming:** exposed as `"<3mA"` in both firmware (`amp<0/1>` response text) and the UI
  button. It does not reach 3mA — it reaches ~3.75mA, which is still above the part's
  rating and yet measurably linear. Suggest renaming to "low-current mode (÷4)" so the
  label doesn't assert something the measurement doesn't support. Not renamed as part of
  this pass.

---

## Square generation

Pico GPIO straight into the TC4427. No op-amp anywhere in this path, which is why edges
measure ~20ns and why square reaches 2MHz while sine stops around 1MHz.

- **Generation method: PIO** (`square_asym_program`, PIO0 SM1) — not a PWM slice, not a
  timer. It runs autonomously once configured: the commanded HIGH/LOW cycle counts are
  pulled into the PIO's persistent ISR/Y registers exactly once, and the wrap loop then
  toggles the pin forever with zero further CPU or FIFO involvement, at the raw
  (undivided) system clock. Frequency is therefore quantized in whole PIO cycles, not a
  phase accumulator — resolution is `1/sys_clk` of period, i.e. coarser in relative terms
  the higher the frequency (≈4.4ns steps at 225MHz, ~0.44% of a 1MHz period, ~0.9% of a
  2MHz period).
- **Duty cycle IS user-settable** (`duty<pct>`, 1.0–99.0%, default 50%) — not fixed. A
  correction is applied by default and can be disabled at runtime (`corr<0/1>`): a base
  27ns HIGH-time cut (`SQUARE_DUTY_CORRECTION_NS`, from the TC4427's t_D1/t_D2
  propagation-delay asymmetry) below ~100kHz, replaced above that by
  `square_duty_cal_curve[]`, a manually-measured correction-vs-frequency table
  (log-frequency interpolated) fitted to a second BNC measurement pass, since the flat
  27ns model alone left a growing residual above 100kHz. **This directly supersedes the
  previous claim that "no correction is currently applied"** — that was true of an
  earlier build; it is not true of the current one. Current measured result
  (`measurements.md`): within ~12ns of 50% and non-monotonic across 1kHz–2MHz, at or
  below the scope's resolution.
- If a systematic pulse-width offset reappears on better equipment, it's correctable by
  extending `square_duty_cal_curve[]` with more measured points — the mechanism already
  exists; it is not a single hardcoded constant to hunt for anymore.

## Output selection
- **Confirmed:** the ADG1419 select line (GPIO10) is driven from firmware, and
  sine/square routing is a host command — every `sine`/`square`/`noise`/`am`/`fm` command
  sets `current_waveform`, and core1's `waveform_changed` handler drives GPIO10
  accordingly (SQUARE routes to 1, everything else — SINE/NOISE/AM/FM all share the DAC
  path — routes to 0).
- **Break-before-make: not implemented in firmware** — there is no explicit dead-time
  delay around the GPIO10 write. This relies entirely on the ADG1419 itself being a
  break-before-make SPDT switch by design (its standard datasheet characteristic). This
  is a part-characteristic claim, not a firmware behavior; it hasn't been independently
  re-verified against the datasheet PDF in this pass.

---

## Additional modes

**Confirmed implemented, all three — not experiments.** `firmware.md` previously listed
only Noise and AM as unconfirmed; **FM is a third fully implemented mode** the previous
version of this document didn't mention at all. All three share the sine DDS path
(`sine_phase_increment`) and are affected by low-current mode; none are mentioned as met
requirements in `version_requirements.md`, which still lists "Modulated signals (AM, FM,
PM, PWM...)" under **Future Versions** — that entry is stale and should move to the met
list (flagged here, not edited, since it's outside `firmware.md`).

- **Noise injection**, requested SNR settable 0–60dB (`snr<db>`).
  **Mechanism:** a Gaussian-ish noise sample (xorshift32 LFSR → Irwin-Hall(12), i.e. the
  sum of 12 uniform draws, crest factor ≈6) is added to the same sine table used for
  SINE mode, sample-by-sample, then clamped to the 8-bit DAC range — one shared PIO/DAC
  path, not a separate one. **SNR is calculated, not bench-calibrated:** the sine
  amplitude and noise sigma are derived from a closed-form budget
  (`A/√2 = s·10^(SNR/20)`, `A + 4s = 127`) assuming ideal Gaussian statistics on the
  ladder codes; it has not been measured against a real bench SNR reading. This matches
  `measurements.md`'s own "Still to characterise: Firmware feature validation: noise-mode
  SNR, AM depth" — i.e. the gap this document flags is the same one already tracked
  there, not a new one.
- **Amplitude modulation**, depth settable 0–100% (`d<number>` while in AM mode).
  **Source/definition:** a second sine phase accumulator at `mod_freq_hz` (`m<number>`)
  modulates the carrier as `carrier · (1 + depth · sin(2π f_m t))`; the carrier itself is
  pre-scaled to `1/(1+depth)` so the envelope peak always lands exactly on full scale and
  never clips, at any depth. The doc's own suggested validation,
  `(Vmax−Vmin)/(Vmax+Vmin)`, is the correct check for this definition and hasn't been run
  yet.
- **Frequency modulation** (undocumented previously): deviation settable in Hz
  (`d<number>` while in FM mode). The carrier phase is advanced by
  `sine_phase_increment + deviation_hz · sin(2π f_m t)` each sample — true instantaneous
  FM, not a fixed-table sweep.

---

## Host interface
- **Transport: USB CDC serial**, not UART, not the Pico W's wireless radio (present on
  the part, unused — `pico_enable_stdio_uart(AWG 0)` / `pico_enable_stdio_usb(AWG 1)` in
  `CMakeLists.txt`). Matches the stated USB requirement in `version_requirements.md`.
- **Command format:** newline-terminated plain text, one command per line, `> ` echoed
  as a prompt after each. Every numeric field is parsed with `atoi`/`atof`, so malformed
  non-numeric input generally reduces to 0 and is rejected by the same range check as an
  out-of-range value — there's no separate parse-error path.

  | Command | Effect | Valid range |
  |---|---|---|
  | `f<Hz>` | Set frequency (all waveforms; SQUARE also re-derives duty counts) | 1–50,000,000 |
  | `c<factor>` | Sample-rate calibration trim (SINE/NOISE/AM/FM only) | 0.5–1.5 |
  | `sine` / `square` / `noise` / `am` / `fm` | Switch waveform | — |
  | `snr<dB>` | Noise SNR (NOISE mode) | 0.0–60.0 |
  | `m<Hz>` | Modulation frequency (AM/FM) | 1–1,000,000 |
  | `d<amount>` | Modulation amount: AM depth % / FM deviation Hz | 0–100,000 |
  | `duty<pct>` | Square duty target | 1.0–99.0 |
  | `corr<0/1>` | Square duty-cycle correction on/off | 0 or 1 (any non-zero = on) |
  | `amp<0/1>` | Low-current (`<3mA`) mode on/off | 0 or 1 (any non-zero = on) |
  | `i` | Print full current state | — |

- **Error handling: outright rejection, not silent clamping** — for every range-checked
  command (`f`, `c`, `snr`, `m`, `d`, `duty`) an out-of-range value prints
  `"Invalid ..."` and leaves the parameter unchanged. The two newest commands, `corr` and
  `amp`, have no invalid case at all: any non-zero parse result is "on", anything else
  (including unparseable text, which `atoi` reduces to 0) is silently "off" — a minor,
  real inconsistency worth knowing about rather than a bug to fix here.
- **What the UI exposes, and what it doesn't:** `scripts/awg_ui.py` (Tkinter) exposes
  waveform mode buttons (sine/square/noise/am/fm), frequency/calibration/SNR/mod-freq/
  mod-amount dials, and the `<3mA` amplitude toggle. **It does not expose `duty` or
  `corr` at all** — square duty and its correction are reachable only over raw serial,
  with no control surface in the host UI and no way to send an arbitrary raw command from
  it either. That's a real gap, not an oversight to paper over in this doc.

### Not implemented
- Continuous digital amplitude control. The ÷4 toggle is a step function, not a control.
- Self-assessment / signal-quality reporting in the UI (jitter, THD, amplitude error,
  spurs), which is a stated requirement for the future UI.
- Standalone operation without a PC.
- Square duty/correction controls in the host UI (see above).

---

## Open firmware-side questions
1. Whether the DDS paths' Nyquist limit (~2.017MHz) should be enforced in the `f`
   command, given it currently accepts up to 50MHz for every waveform and aliases
   silently above ~2.017MHz for SINE/NOISE/AM/FM.
2. Whether `square_duty_cal_curve[]` needs more measurement points, or whether the
   current 8-point curve already keeps the residual within the scope's ~10ns division
   everywhere in 1kHz–2MHz.
3. Whether noise/AM/FM should be promoted out of `version_requirements.md`'s "Future
   Versions" list now that they're implemented and running, and what "shipped" should
   require (see `measurements.md`'s outstanding SNR/depth validation).

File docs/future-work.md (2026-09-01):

# Future Work

This document lists features, improvements, and extensions that are
intentionally postponed to preserve focus and momentum. May or may not be developed.

## High Priority

### Digital amplitude control
- Firmware R-2R lookup-table scaling (deferred from v1.0/v1.1, which ship with an analog pot).
- Potentially combined with coarse analog gain switching.

## Lower Priority

### Discrete parts
Building the generator using only discrete components.

### High-frequency extensions
- Extend clean sine generation beyond the initial MHz range
- Investigate RF-specific PCB layout techniques
- Separate low-frequency/high-voltage and high-frequency/low-voltage paths

---

### Output stage improvements
- Higher-voltage output capability (40–50 Vpp at low frequency)
- Selectable output impedance (50 Ω / Hi-Z)
- Improved output protection for misuse scenarios

---

### Signal quality improvements
- Lower phase noise / jitter through improved clock sources
- Better reconstruction filtering strategies

---

### User interface extensions
- Onboard OLED display and rotary encoder
- Standalone operation without PC
- Preset storage and recall

---

### Calibration & metrology
- Automated self-calibration routines
- Temperature drift characterization
- Improved self-reporting of signal quality metrics

---

### Advanced modulation & communications
- Digital modulation schemes (FSK, PSK, ASK)
- External modulation inputs
- Use as a basic signal source for communications experiments

## Final Stage

### Pico Integration
- Integrate MCU inside the PCB
- Use of USB C
- Proper application instead of vscode

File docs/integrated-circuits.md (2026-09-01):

# ICs currently in use

- `LM318` for the non-passive sinewave stages: DAC buffer and gain stage.
    Chosen for its high slew rate and cheap price. 5pF external compensation per stage.
    Not present in the square path at all — see below.
    There is no separate output buffer; the gain stage drives the switch and the output
    network directly. Bandwidth note: GBW ~15MHz, so closed-loop bandwidth in the gain
    stage falls as the pot is turned up. Slew rate ~70V/µs sets the large-signal limit,
    and ~±20mA output current is what restricts the instrument to Hi-Z loads.

- `ADG1419` SPDT analog switch: selects sine or square at the output.
    Low Ron, runs on the ±9V rails, break-before-make. LFCSP package
    (thermal/VEE pad served by a VEE island on the bottom layer).
    Sits ahead of the 50Ω series resistance, so its Ron (~2.1Ω) adds to the source
    impedance in both modes — measured 53Ω sine vs. nominal 50Ω is consistent with Ron
    alone. Square measures higher still (58Ω); the extra ~5Ω there is the TC4427's own
    output resistance, not the switch — see its entry below.

- `TC4427` gate driver used as squarewave buffer.
    Fast, clean edges from the Pico GPIO; comfortable driving capacitive loads.
    19ns typical rise/fall, which matches the ~20ns measured at the BNC. Because the
    square path goes Pico -> TC4427 -> ADG1419 -> BNC with no op-amp in between, the
    TC4427 and the switch set the edge rate, and the square path reaches 2MHz while the
    sine path is limited to ~1MHz. The same lack of buffering is why square's source
    impedance (58Ω measured) runs higher than sine's (53Ω): with no op-amp downstream to
    absorb it, the TC4427's own output resistance adds directly in series with the
    ADG1419 and the 50Ω resistor, on top of what the switch alone contributes.

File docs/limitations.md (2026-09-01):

# Current Limitations

## Equipment

### Measuring tools
    Oscilloscope smallest division is 10ns. Edge rates around 20ns are therefore
    only ~2 divisions wide and should be read as approximate.
    Probes add visible parasitic capacitance at higher frequencies.
    No THD or jitter measurement capability — those specs remain uncharacterised.

## Hardware

### R-2R Resistors
    - Ladder uses 2.2kΩ 1% thick film (the only Basic part available at JLCPCB).
    - Matching at 1% limits monotonicity around the MSB; effective DAC linearity ~7 bits worst-case.
    - 0.1% thin film is the known upgrade path for a future revision (costed, deferred).

### Filter inductors — under-rated for current
    - Rated current is 3mA. Actual peak current through L1 at full scale is ~15mA.
    - Consequence: the ferrite saturates, producing passband insertion loss well below
      the corner. Measured -3.1dB at 1MHz where the design predicts ≤0.3dB.
    - Mitigation in firmware: a low-current mode drops DAC amplitude by 4 via the R-2R
      lookup table, bringing peak current to ~3.75mA. The passband goes flat (-0.09dB at
      1MHz). Cost: 4x less output amplitude and two bits of resolution, leaving ~5
      effective bits.
    - This is a workaround, not a fix. The fix is a higher-saturation-current 10µH in
      0805/1206. See lessons.md #4.
    - ±10% tolerance: filter corner may shift a few % board-to-board.
    - SRF 17MHz: stopband attenuation degrades above ~17MHz. Acceptable — with the chosen
      sample rate the strong DAC images land below SRF.
    - Q = 30 at 2MHz, i.e. ~4.2Ω effective series resistance against a 1.85Ω DCR.
      Finite Q in a doubly-terminated ladder adds droop toward the corner.

### Filter corner below simulation
    - Simulated 1.5MHz, measured ~0.98-1.00MHz, in both drive modes.
    - Unexplained. Saturation accounts for the passband loss but not the corner shift —
      falling inductance should move the corner up, not down. Finite Q and ±10%
      tolerance stacking across six reactive parts are the remaining candidates.

### Low-frequency operation
    - AC coupling corner is ~1.3Hz. Very-low-frequency signals near the corner put real AC
      across the polarized coupling cap. The "0Hz" spec is nominal, not tested territory.
    - The corner is calculated, not measured.

### Output amplitude
    - Max sine is ~16Vp-p (8V peak) at 1kHz on ±9.5V rails. The 9V peak requirement is
      not reachable with an LM318 on this supply.
    - Amplitude falls to ~7Vp-p at 1MHz at a pot setting giving 10Vp-p at 1kHz.

### Amplitude control
    - Analog potentiometer only in this build. Digital amplitude control is deferred
      (firmware R-2R lookup-table scaling planned).

### Squarewave amplitude
    - Fixed. The square path runs Pico -> TC4427 -> switch -> BNC with no gain stage,
      so amplitude is set by the TC4427 supply and cannot be varied.
    - Variable squarewave gain is listed as a future requirement.

### Hi-Z loads only
    - There is no output buffer. The gain-stage LM318 drives the switch and the output
      network on its own, and can source roughly ±20mA.
    - Into a 50Ω terminated load, full swing would demand ~80mA. The instrument cannot
      deliver rated amplitude into 50Ω; Hi-Z is a constraint, not a preference.
    - The 50Ω series resistor sits after the switch and is the same physical component
      for both modes, but measured source impedance differs by mode: 53Ω sine, 58Ω
      square at 1kHz (`measurements.md`) — sine picks up the ADG1419's Ron, square adds
      the TC4427's own output resistance on top of that.

# Intentional Limitations
    Early revisions (breadboard, v1.0) accepted parasitics and noise
    in exchange for rapid iteration and learning.

    The v1.2 PCB is the first completed version: all-SMD, single board, solid ground plane.
    Remaining intentional non-idealities: BNC and Pico hand-soldered, 1% ladder and
    ±10% inductors accepted for cost and Basic-part availability.

    The Pico is soldered directly on v1.2 with no socket, so it is not swappable
    without rework.

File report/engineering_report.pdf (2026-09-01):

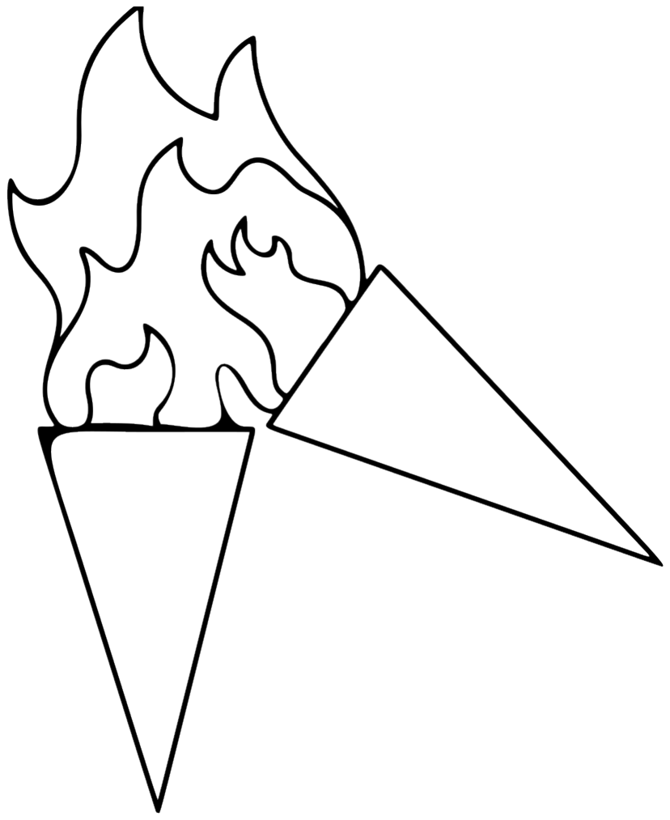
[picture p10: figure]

# AWG / DDS Function Generator

## Engineering Process Report

How we got here

Current build: v1.2 — working, characterised

Three PCB revisions; two arrived dead

Lambros25

lambros25savva@gmail.com

September 1, 2026

Compiled from the timestamped engineering logs, the documentation set, and the current state of the repository. Figures and dates are cited to their source throughout; see About this report for what is and isn’t drawn from the logs.

AWG / DDS Function Generator | Engineering Process Report | | 1

## Contents

Summary | | 2
1 About this report | 2
2 Project at a glance | 3
3 Timeline | 3
4 What went wrong | 9
5 What went right | 9
6 Lessons and rules derived | 10
7 Current state — v1.2 | 11
8 Open items and future work | 11
Appendix A: source material | 13
Appendix B: current schematic (v1.2) | 14

## Summary

Why? How?

### 0.1 Why?

This project was aimed to be above all else, a learning experience with a byproduct of a working function generator. It was an excuse work with digital analog synthesis, signals, filters, opamps and even switches. A gateway to mixing analog and digital, build intuition and experience. Along with that, having a set goal, a tool for proof helped with rough prototyping days, as well as motivation.

### 0.2 How?

The idea begun with an arbitrary wave generator. It’s in theory, a generator that can output any wave, ideally at any frequency with unlimited power. With as a template, after online research the goal of 1MHz was established, using a raspberry pi pico W. The pi pico outputs using an R-2R ladder "steps", that is samples of the requested signal, and using the proper filters and reconstruction methods, the full signal is recovered. Ideally the project would follow a R-2R -> Reconstruction -> Buffer -> output diagram, which it mostly did with the exception of a variable gain stage, as the pico is limited to +3.3Vp-p. Moreover, due to the lack of a proper power supply, it was designed around 2 x 9V rechargable batteries.

### 0.3 The Arbitrary Wave Generator (AWG)

The instrument itself is a laboratory-oriented DDS/AWG signal generator built around an R-2R ladder, a 5th-order doubly-terminated LC Butterworth reconstruction filter, and a Raspberry Pi Pico W. It uses lm318 at 3 stages, during reconstruction, amplification and buffering, as well as an TC4427 for squarewave buffering and an ADG1419 for output selection. It produces sine, square, noise, AM and FM under USB control, it is characterised from DC to 1 MHz on the sine path and to at least 2 MHz on the square path, and has a known, documented, firmware-mitigated fault in its filter that is described here rather than smoothed over.

## 1 About this report

This is a process report, not a design document. It exists to answer how did we get here, not to restate what the instrument does — the documentation set already covers that, in design-philosophy.md (https://github.com/Lambros25/Function-Generator/blob/main/docs/design-philosophy.md) for intent, v1_2_architecture.md (https://github.com/Lambros25/Function-Generator/blob/main/docs/v1_2_architecture.md) for the current architecture, and measurements.md (https://github.com/Lambros25/Function-Generator/blob/main/docs/measurements.md) for numbers. This report’s job is the timeline and the honesty around it: what was tried, what worked, what didn’t, and what it cost.

Sourcing. Every dated event below is read from the timestamped engineering logs (18 files, 27 January – 1 September 2026) and cross-checked against lessons.md, (https://github.com/Lambros25/Function-Generator/blob/main/docs/lessons.md) version_requirements.md (https://github.com/Lambros25/Function-Generator/blob/main/docs/version_requirements.md) and measurements.md (https://github.com/Lambros25/Function-Generator/blob/main/docs/measurements.md) for figures the logs state only loosely. Where a claim comes from a log entry it is cited by filename, so it can be checked against the original. A complete index of those files is in the source-material appendix.

One gap in the record

The logs contain no entry at all for v1.1’s failure. That account (Section 3.5) was supplied directly by the author while reviewing this draft rather than found in the source material. It is flagged as such where it appears, and in the appendix, rather than presented as if it were logged like everything else here.

What this is not. It is not a substitute for lessons.md (https://github.com/Lambros25/Function-Generator/blob/main/docs/lessons.md) — the rules derived from failure live there, and this report narrates the failures that produced them. It is not a spec sheet either; that is the top of README.md. (https://github.com/Lambros25/Function-Generator/blob/main/README.md)

## 2 Project at a glance

Instrument summary — v1.2

Waveforms | Sine, square, sine+noise, AM, FM
Sine range | 0 Hz–1 MHz, characterised; DDS with phase accumulator
Square range | To at least 2 MHz
Sine amplitude | ∼16 Vpp max at 1 kHz, analog pot
Square edges | ∼20 ns rise and fall, 10–90%
Output impedance | 53 Ω sine / 58 Ω square, measured at 1 kHz
Resolution | 8-bit R-2R ladder, ∼7 effective bits
Supply | USB and 2×9 V batteries
Control | USB CDC serial and desktop UI (scripts/awg_ui.py) (https://github.com/Lambros25/Function-Generator/blob/main/scripts/awg_ui.py)
MCU | Raspberry Pi Pico W (RP2040), overclocked to 225 MHz

Full current numbers are in measurements.md; (https://github.com/Lambros25/Function-Generator/blob/main/docs/measurements.md) the full specification table is at the top of README.md. (https://github.com/Lambros25/Function-Generator/blob/main/README.md)

Version | What changed | Outcome
v0.x | Breadboard. R-2R DAC, discrete and op-amp filtering, dis- crete square path. | Architecture validated
v1.0 | First PCB. Mixed THT/SMD, 4× cascaded RC filter. | Dead on arrival — BOM
v1.1 | All-SMD, LC Butterworth reconstruction filter. | Dead on arrival — schematic
v1.2 | As v1.1, with the LM318 short fixed and the Pico soldered direct. | Working, characterised
Jan | Feb | Mar | Apr | May | Jun | Jul | Aug | Sep

Project
start

Compromise
to ICs

v1.0
DOA

v1.2
working

first clean
1 MHz sine

v1.0
ordered

v1.1
DOA
discrete square detour | paused — exams

Figure 1: Eight months, January to September 2026. Two of the three PCB revisions arrived dead; the gap between them is exam season, not debugging.

## 3 Timeline

### 3.1 Breadboard era: R-2R, filtering, and a lot of noise

The project started from nothing on 27 January 2026: Pico toolchain installed, Zadig drivers for USB, and a first, crude R-2R ladder built from 10 kΩ/20 kΩresistors, driven by AI-generated test firmware for speed. Quality visibly degraded past 60–70 kHz and the ladder was usable to about 200 kHz; pushed hard, the bare Pico GPIO could toggle at up to ∼10 MHz, which set an early —
and, in hindsight, over-optimistic — sense of headroom. | Source: EngLog 27-01-26 - 0324.txt

By 18 February the ladder had been changed to 2.2 kΩ/1.1 kΩ(two 2.2 kΩin parallel) for better linearity, and serial frequency control was working end to end after a rewrite of the host I/O code. 1 MHz looked reachable, by the log’s own hedged wording (“seems that I can manage”), but nothing had been done to condition or verify that signal yet: the buffer and filter parts it
would take to find out were still on the order list. | Source: EngLog 18-02-26 - 1750.txt

The next entry is the first real filtering attempt: a TL082 unity buffer straight off the ladder, followed by two RC low-pass stages (470 Ω/220 pF) and a second buffer. Usable to 100–200 kHz; at 1 MHz the signal showed ∼50% amplitude loss, roughly 1 V of DC offset, and visible jitter and ghosting. Square-wave firmware was added in parallel but not yet seriously characterised,

pending a better op-amp. | Source: EngLog 19-02-26 2036.txt


Figure 2: Breadboard sine chain during the RC-filter era: R-2R ladder, buffering and cascaded filter stages, before the move to LM318 and, later, to a PCB.

24 February added a high-pass stage immediately after the ladder to strip the DAC’s DC bias, a 10 kΩpotentiometer as a first amplitude control, decoupling (100 nF + 10 µF) at the op-amp rails, and the first schematics committed to the repository. LM318 buffers, solid-core wire and a

perfboard were ordered. | Source: EngLog 24-02-26 2100.txt


Figure 3: First quality check against a bench generator at 1 MHz, breadboard build.

The Sallen-Key detour. With LM318s in hand on 27 February, a full day went into active Sallen-Key filtering, using parallel resistor and capacitor networks to hit non-standard ratios. Results were persistently noisy, worse under load, and worse still through the gain stage. Four candidate causes were ranked in the log itself — parasitic capacitance and poor breadboard contact as the top suspect, the unorthodox filter/buffer layout, bad R-2R contacts newly exposed by the better op-amp, and general wiring and grounding — with a closing line that reads, in hindsight, like the project correctly diagnosing its own next two failure modes:

“the brief moments of clean signal with each stage tells me its something less. . . systemic.”

Source: EngLog 27-02-26 0000.txt

First major success. The very next day, active filtering was abandoned entirely in favour of five cascaded passive RC stages (four 470 Ω/221 pF low-pass, one 100 µF/1 MΩhigh-pass), a dedicated inverting gain stage (1 kΩ input, 0–10 kΩ feedback pot, 5 pF compensation) for rail-to-rail swing, a further low-pass stage to clean up noise the gain stage had uncovered, a voltage-follower output buffer, and a 47 Ω series resistor into a BNC connector — effectively the topology that would carry through to the PCB. The result was clean, with no ghosting and only a slight “vibration” at 1 MHz that the log is honest about not being able to attribute to the circuit rather than the

oscilloscope. | Source: EngLog 28-02-26 0003.txt


Figure 4: 1 MHz sine capture from the breadboard build, taken around the first major success (28 February 2026).

### 3.2 The discrete square-wave detour

Later the same day, breadboard contact problems fried an LM318 — a feedback loop opened under a loose contact. The decision was made to accept the sine chain’s Hi-Z-only, no-current-drive limitations as a deliberate trade for lower parasitics, add square-wave and arbitrary-waveform
output, and move toward a first PCB. | Source: EngLog 28-02-26 1709.txt

What followed was roughly two weeks of discrete-transistor square-wave buffering, pursued specifically to build real experience with current amplification rather than reach for an IC immediately.

- 1 March. Decision to go discrete; parts ordered. | Source: EngLog 1-03-26 1637.txt
- 3 March. Parts arrive. A hand-derived current amplifier, biased to remove the ∼0.7 V junction drop, worked in SPICE but not on the bench. GPIO8 was burned by inserting a capacitor believed, incorrectly, to be discharged — a direct hardware casualty rather than a
design flaw. | Source: EngLog 3-3-26 2336.txt

- 13 March. First working square-wave buffer prototype, limited to below ∼50 kHz with
rounded edges. | Source: EngLog 13-03-26 2007.txt
- 25 March. An unconventional totem-pole push-pull stage reaches a 1 MHz square wave — noisy, with a duty-cycle asymmetry the log calls “duty cycle variety”, and limited by a ∼1 kΩ input impedance, visible heating in the transistors and resistors, and the battery’s own current
capacity. | Source: EngLog 25-03-2026 1739.txt
- 27 March. The duty-cycle and frequency-mismatch bugs are traced to the first PNP pair’s 9 V rail, and removing it fixes the 1 MHz case — but only at high frequency; the fix did not
carry down to the low-frequency case. | Source: EngLog 27-03-26 0031.txt


Figure 5: The discrete-transistor square-wave buffer on breadboard, from this detour — the circuit itself, not a captured output waveform.

### 3.3 Compromise: ICs, requirements, and a PCB

After the holidays, and after posting for help online without result, the log records a deliberate compromise: continuing the discrete-transistor path risked never shipping a working instrument. V1 requirements were fixed — sine and square from 0 to 1 MHz at 9 V peak, digitally adjustable amplitude, PC control via the Pico W, a durable PCB, strong documentation, BNC output, USB and battery power, and Hi-Z loads only — and the square path moved to a TC4427 gate driver, with amplitude control via adjustable LDO rail limiting (LT3080/LT3090) and a digital pot.

Parts for that scheme were ordered, but neither made it onto the PCB. Simulation showed the LDO rails degrading the square wave itself, and the digital pot turned out to be unavailable in the resistance range needed or in a DIP package — and would have added noise of its own even

if it had been. | Source: EngLog 20-04-26 0103.txt
Project work was then paused through May and into June for exams. | Source: EngLog 01-05-26

1714.txt

### 3.4 v1.0: first PCB, dead on arrival

The first PCB was designed and ordered as a mixed THT/SMD board — filtering kept throughhole for rework access, given how differently breadboard and PCB parasitics were expected to behave — using the four-stage cascaded RC filter from the breadboard build. The rail-limiting amplitude-control scheme from April was tried and dropped: it caused visible waveform rounding, so amplitude reverted to a simple variable resistor for this revision. Source: EngLog 6-7-26 1439.txt

The board arrived, and the failure was immediate and total. The BOM matcher had substituted 2.21 Ω resistors for 2.21 kΩ across the entire R-2R ladder: three orders of magnitude off, on every
rung. This is Lesson 1 in Section 6. | Source: EngLog 19-07-26 1656.txt

The same log entry records the immediate pivot: send the board for a respin, replace the four cascaded RC stages with a 5th-order doubly-terminated LC Butterworth filter (∼1.5 MHz cutoff, C0G capacitors, 0603 inductors), and move to a fully SMD, JLCPCB-assembled board. The RC cascade was already a known amplitude bottleneck by this point — each stage ate into the signal well before its own corner — and researching filter topologies at the time made the Butterworth’s flatter passband and steeper rolloff the obvious replacement, independent of the BOM failure that forced the respin anyway.


Figure 6: v1.0 (left) and v1.1 (right) side by side — the two boards that arrived dead. v1.0’s 2.21 Ω ladder and cascaded-RC filter section are visible at top left; v1.1 already carries the LC Butterworth (L1/L2), the soldereddown Pico and the panel-mount BNC that would carry through to v1.2.

### 3.5 v1.1: Butterworth redesign, dead on arrival

This version arrived, was soldered up, and went straight to testing — to no output at all. The ladder’s test point showed nothing and the board was completely silent, with no immediate way to tell whether the cause was power, firmware or a bad contact.

Pivoting to the square path as a diagnostic step paid off: it worked, and worked well, with only some edge ringing that turned out to be a probing artefact — it disappeared once the scope ground lead was shortened — rather than a property of the signal. With sine dead and square clean, the fault was narrowed to the sine chain specifically.

Going over the board repeatedly turned up the cause: a stray trace, left behind during the KiCad-to-Altium migration, shorting the two inputs of the first-stage LM318. The board’s layout, combined with not having a hot-air rework station on hand, made it impractical to confirm that this was the only fault by reworking and re-testing in place. After signal insertion at the DAC test point, the rest of the board proved functional at the lower frequencies the available handheld generator could produce. With the schematic fix in place, v1.2 was ordered directly.

No log entry documents this failure or its diagnosis. The account above was supplied directly by the author, and lessons.md (https://github.com/Lambros25/Function-Generator/blob/main/docs/lessons.md) #3 is the only other place it is summarised.

### 3.6 v1.2: working build

With the LM318 short fixed, power LEDs added and costs trimmed in several places, the board came up clean: tested before assembly, then the Pico soldered directly on. A desktop host

UI was added, along with noise, AM and FM modes on the firmware side. The log calls the project “officially completed” at this point, with bugfixes, additional firmware features and full
characterisation flagged as the next phase rather than as open requirements. | Source: EngLog

01-09026 0306.txt


Figure 7: v1.2 as designed: Altium 3D render and copper layout, August 2026 — the board that was ordered.


Figure 8: v1.2 as built: the board that arrived, assembled, with the Pico soldered directly on and the gain pot and BNC hand-fitted.

The very next log entry is where characterisation starts paying off. Full-drive sine flatness measurements surface a −3.1 dB droop at 1 MHz, and scaling the DAC lookup table by four in firmware eliminates it entirely with no hardware change — which is what pins the cause on inductor saturation rather than on the filter design or op-amp bandwidth (Lesson 3, Section 6). It is diagnosed cleanly and, so far, patched only in firmware; the real fix is expected to be small, swapping L1/L2 for parts with adequate saturation current, likely reworkable on the existing board rather than the kind of fault that forces another respin. A firmware fix for the square
wave’s duty-cycle asymmetry is logged in the same entry. | Source: EngLog 01-09-2026 1436.txt

## 4 What went wrong

- Every failure that cost a board was invisible to every check that was not a physical measurement. A BOM matcher dropping a unit prefix (Lesson 1), a copy-paste merging two nets across an EDA migration (Lesson 2), and a datasheet column never read (Lesson 3). None was caught by ERC, DRC, simulation or visual schematic review. A fourth, closely related near miss — name and part-number drift in the component library, folded into Lesson 1 alongside the BOM matcher — was caught early enough to cost nothing, which is the only reason it reads as a near miss rather than a fourth incident.
- The Butterworth filter’s inductors were selected on inductance, package, tolerance and self-resonance — and not on current rating (Lesson 3), in a 60 Ω system where fullscale drive pushes real current through them. No simulation would have surfaced it: LTspice’s ideal inductor has no saturation current to violate.
- Real hardware casualties from real mistakes. An LM318 fried by a loose breadboard contact opening its feedback loop, and GPIO8 burned by inserting a capacitor assumed, wrongly, to be discharged (both Section 3.2). Both are logged plainly, in keeping with this project’s own standard for honesty.
- Two weeks on a discrete square-wave buffer that gave way to an IC anyway. Not a wasted two weeks — Section 5 credits the experience — but the log’s own tone by late March (“I have realised I grew tired and I’m in way too deep”) is a real signal that the discrete-only constraint was fought past the point of being useful, and should have been reconsidered sooner.
- A public request for feedback that produced nothing usable, noted once and not revisited — worth knowing before trying that channel the same way again.
- No hot-air rework station on hand when v1.1’s LM318 short was found (Section 3.5). With the fault physically identified, the board’s layout and the lack of that one tool made it impractical to confirm it was the only fault by reworking in place, so a full respin was ordered on a diagnosis that could not be closed out on the bench first.
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

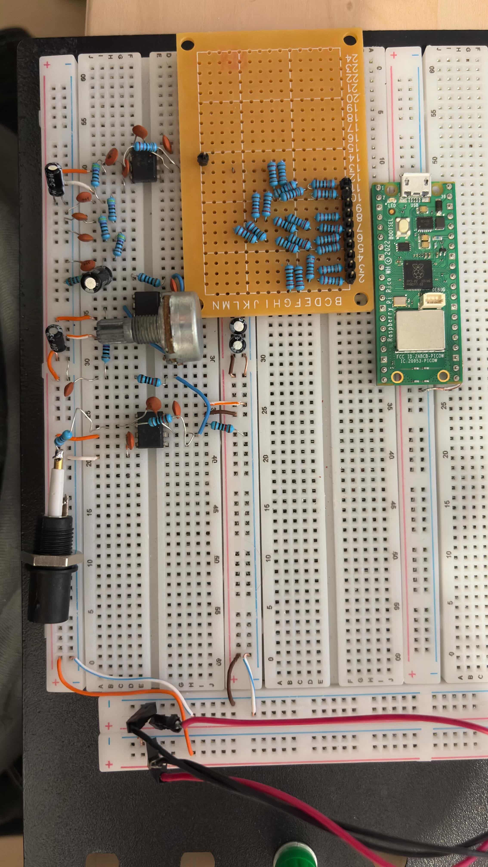
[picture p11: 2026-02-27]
images/sinewave circuit.jpg

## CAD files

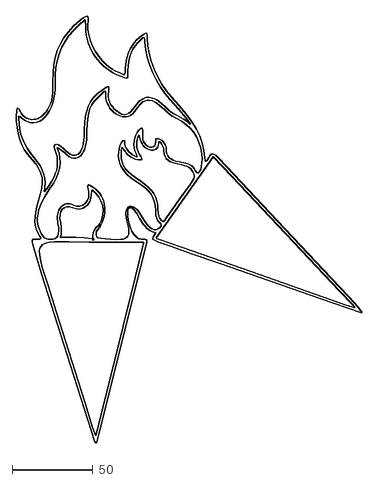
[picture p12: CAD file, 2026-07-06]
hardware/altium/logo.dxf
214.2 x 264.5

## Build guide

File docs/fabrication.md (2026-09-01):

# Fabrication (v1.2)

## Board
- 70x70mm, 2-layer FR-4, all-SMD.
- Single uninterrupted GND pour on bottom layer. -9V and +9V as wide traces and local
  pours on top.
- VEE copper island on bottom layer under the ADG1419 thermal pad (resolves GND/VEE mismatch).
- Ground stitching vias around op-amps.
- Standard via: 0.6mm outer / 0.3mm drill (JLCPCB annular ring + drill minimums).

## DRC calibration
- Altium defaults are conservative vs. JLCPCB and generate false positives.
- Thresholds aligned to process limits: 0.15mm silk-to-silk, 0.1mm solder mask sliver.
- Component-scoped rules (e.g. OnComponent for the LFCSP) preferred over global overrides.

## JLCPCB order
- Economic PCBA: 5 boards fabricated, 2 assembled, 3 bare spares.
- U1 (Pico) and test points intentionally have no JLCPCB part number.
- Hand-soldered after delivery: BNC connector and the Pico. The Pico is soldered
  directly to the board on v1.2, not socketed. Everything else is SMD and machine-placed,
  including the potentiometer.

## Extended fee strategy
- Pay: core ICs (LM318, ADG1419, TC4427), electrolytics (no Basic SMD electrolytics
  exist), C0G filter caps (dielectric is the design intent), and the input/output
  connectors, where contact quality is the point.
- Swap to Basic: decouplers (C28233), anything where only the value/function matters.
- Note: Extended passives carry minimum purchase quantities that inflate component cost.
- Retrospect: chasing Basic parts for the filter inductors is what produced the
  under-rated-current limitation. The saving was real; so was the -3dB it cost at 1MHz.
  Cheapest-Basic is a valid default for decoupling and a bad default for anything in the
  signal path. See lessons.md #4.

## BOM workflow
- LCSC Part # lives as a parameter in the `lambros25` library — every placement inherits it.
- Audit via Tools -> Parameter Manager (grid view of all part numbers at once).
- Before paying: read the matched part DESCRIPTION of every line on the review page.
  Value AND unit. See lessons.md.
- For any part in a low-impedance signal path, check current rating on the datasheet,
  not just value/package/tolerance.
- Placement render check: polarity of electrolytics and LEDs, pin 1 of all ICs
  (especially the LFCSP, where a rotation is invisible on the pads).
- After any cross-EDA import: ERC plus cold continuity check on op-amp input pins.

## Shipping (EU / Cyprus)
- VAT (19%) collected at checkout on merchandise + shipping — every dollar saved
  in the BOM saves 1.19 at the total.
- Economy shipping tiers save ~half vs. courier; only latency changes.

## Git
- Repo tagged per fabrication submission so docs snapshot matches shipped Gerbers.

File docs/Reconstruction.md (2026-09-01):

# Current sinewave reconstruction method

## First Stage: Sinewave DAC

- `2.2kΩ single-value R-2R Ladder`
    2.2kΩ 1% thick film for the 2R nodes, two in parallel for the R nodes.
    Same-reel strategy: one BOM line for the whole ladder (plus LED droppers etc.),
    minimizes cost and eliminates value-mixup risk.
    Resistor ladder allows much higher update rates than PWM approaches.
    Couldn't use smaller R values as current would be too high for Pi Pico W pins.
    1% tolerance accepted (only Basic part available) — limits effective linearity
    to ~7 bits; 0.1% thin film is the future upgrade (see limitations.md).

- `lm318` buffer
    Using the recommended layout. Buffering and 5pF compensation handled at the
    DAC output, ahead of the filter.

## Second Stage: Reconstruction Filter
    - 5th-order doubly-terminated LC Butterworth low-pass.
    - Topology: shunt C - series L - shunt C - series L - shunt C
    - Values: 1nF - 10uH - 3.3nF - 10uH - 1nF
    - System impedance: 60Ω, built as 2x 120Ω in parallel on BOTH source and load side
      (same reel as the rest of the board).
    - Caps: C0G ±1% (X7R would add distortion in the signal path — dielectric matters here).
    - Inductors: 0603, ±10%, SRF 17MHz, DCR 1.85Ω, rated current 3mA, Q=30 at 2MHz.
      Only Basic part available. The current rating turned out to be the design error
      of this revision — see lessons.md #4.
    - Replaced the previous 4x cascaded RC LPFs: maximally flat passband instead of
      stacked droop, -100dB/decade rolloff, purely passive so it adds no noise and no
      op-amp bandwidth limits.
    - Cost of the topology: fixed -6dB from double termination, recovered in the gain stage.

### Cutoff: simulated vs measured
    - Simulated (LTspice, ideal parts): ~1.5MHz, ~-0.1dB at 1MHz.
    - Measured: corner sits at ~0.98-1.00MHz in both drive modes.
    - The corner is stable with drive level; what changes with drive level is passband
      LOSS, not corner frequency. At full drive the chain reads -3.1dB at 1MHz; in
      low-current mode it is flat to within 0.1dB.
    - Cause of the loss: ferrite saturation. ~15mA peak flows through L1 at full scale
      against a 3mA rating. A saturating ferrite loses permeability and gains core loss,
      which produces insertion loss well below the corner — exactly the observed shape.
      Confirmed by a firmware-only test: scaling the lookup table by 4 removed the
      entire -3.5dB droop with no hardware change.
    - OPEN: the corner shift from a simulated 1.5MHz to a measured ~1.0MHz is still
      unexplained. Saturation accounts for the loss, not the shift — if anything,
      falling inductance should move the corner UP. Remaining candidates are finite Q
      (Q=30 at 2MHz backs out to ~4.2Ω effective series resistance, well above the
      1.85Ω DCR) and ±10% tolerance stacking across six reactive parts. Adding ~4Ω in
      series with L1/L2 in LTspice is the next test.

## Third Stage: AC Coupling
    - 100uF electrolytic, HP corner ~1.3Hz. Removes the DAC's DC offset.
    - Polarized: DAC side sits at positive DC bias, so orientation matters (+ toward DAC).
    - Series coupling caps (high-pass sections) appear after the reconstruction filter
      and again after the gain stage. Between them, measured DC offset at the BNC is nil.

## Fourth Stage: Amplification
    - lm318 inverting amplifier. 1kΩ input resistor, 10kΩ potentiometer feedback.
    - Stage gain Rf/Rin is up to 10, but end-to-end gain from the DAC buffer is lower:
      the filter is doubly terminated (-6dB) and the 1kΩ input resistor loads the 60Ω
      termination (60‖1k ≈ 56.6Ω), giving a practical end-to-end maximum of roughly x4.85.
    - Pot is a temporary placeholder — digital amplitude control planned.

## Fifth Stage: Output Network
    - No output buffer. The gain stage drives the ADG1419 directly; the switch drives
      the output network on its own.
    - 50Ω series output resistance (2x 100Ω in parallel) sits AFTER the switch, so it is
      shared by the sine and square paths and the 50Ω source spec holds in both modes.
    - Consequence: the gain-stage LM318 is the only device driving the output. Fine into
      Hi-Z; it cannot deliver full amplitude into a 50Ω terminated load (~80mA required
      at full swing against ~±20mA available). Hi-Z loads are a constraint, not a
      preference.

## Squarewave path
    - Pico GPIO -> TC4427 driver/buffer -> ADG1419 analog switch -> 50Ω -> BNC.
    - The square path contains NO op-amp. This is why edges measure ~20ns: an LM318
      slewing a ~10.8V swing at ~70V/µs would take ~150ns. The edge rate is set by the
      TC4427 (19ns typical) and the switch.
    - It is also why square reaches 2MHz while sine tops out around 1MHz — the two paths
      have genuinely different bandwidth limits.
    - The ADG1419 selects sine or square; both share the output network and the BNC.

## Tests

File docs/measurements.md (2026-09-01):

# Current measurements

All measurements taken at the BNC unless stated otherwise.
Supply: 2x 9V batteries. Scope smallest division 10ns — treat sub-10ns figures as bounds.

## Rails
- V+: 9.52V
- V-: -9.54V

---

## Sinewave — full drive
Pot fixed so that Vp-p at 1kHz is 10.00V. Real max is ~16Vp-p at 1kHz.

| Frequency | Vmax | Vp-p | dB re 1kHz |
|---|---|---|---|
| 1kHz | 4.79V  | 10.00V  | 0 |
| 10kHz | 4.78V  | 9.98V | -0.02  |
| 100kHz | 4.71V  | 9.92V | -0.07  |
| 300kHz | 4.36V  | 9.30V | -0.63  |
| 500kHz | 4.14V  | 8.96V | -0.96  |
| 700kHz | 4.03V  | 8.64V | -1.27  |
| 1MHz | 3.50V  | 7.00V | -3.10  |

Note: Vmax and Vp-p are not self-consistent at the low frequencies (4.79V against a
10.00V swing implies Vmin = -5.21V), yet no DC offset is present at the BNC. Likely
auto-measure taken at different moments.

## Sinewave — low-current mode
DAC lookup table scaled by 4 to reduce current through the filter inductors.
Peak inductor current drops from ~15mA to ~3.75mA. Pot re-set for ~1V p-p at 1kHz.

| Frequency | Vmax | Vp-p | dB re 1kHz |
|---|---|---|---|
| 1kHz | 497.47mV  | 1.01V  | 0 |
| 10kHz | 496.7mV | 1.01V  | 0 |
| 1MHz | 494.7mV | 1.00V  | -0.09  |

The -3.1dB droop at 1MHz disappears entirely at quarter drive, with no hardware change.
This is the confirmation that the droop is ferrite saturation in L1/L2 and not filter
design, op-amp bandwidth or slew limiting. See lessons.md #4.

The flat curve is the diagnosis, not the spec. As the instrument ships it runs the
ladder at full scale, so -3.1dB at 1MHz remains the honest number. Cost of the mode:
two bits of an already ~7-bit-effective ladder, so ~5 effective bits.

## DC offset
- None observed at the BNC. AC coupling removes the DAC's DC bias; additional filtering
  after the reconstruction filter and after the output buffer keeps the baseline clean.

---

## Output impedance
Measured on one unit at 1kHz into a 100Ω load (Vp-p unloaded vs. across the load).

| Mode | Source impedance |
|---|---|
| Sine | 53Ω |
| Square | 58Ω |

Nominal is the 50Ω series resistor after the ADG1419, shared by both modes as a
physical component. The two modes are NOT the same figure, though: sine's +3Ω over
nominal is consistent with the ADG1419's Ron (~2.1Ω) alone; square's +8Ω is not — the
extra ~5Ω is the TC4427's own output resistance, which sits in the square path only
(square goes Pico -> TC4427 -> ADG1419 -> 50Ω with no op-amp buffering in between; sine
has the LM318 gain stage driving the switch instead). This corrects the earlier
assumption that "the 50Ω is shared by both modes, so one measurement covers it" — the
shared series resistor is, but total source impedance isn't, because what's in series
ahead of it differs by mode. Single unit; not yet checked for board-to-board variation.

---

## Squarewave
- Pico can produce signal at least up to 2MHz.
- Amplitude at the BNC: NOT RECORDED — measure.

### Edge rate (10-90%, at the BNC)
- Rise: ~20ns
- Fall: ~20ns (symmetric)
- Consistent with the TC4427's 19ns typical. The square path contains no op-amp, so the
  edge is set by the driver and the switch, not by LM318 slew rate.
- ~20ns is ~2 scope divisions; treat as approximate.
- Amplitude: 8.80V

### Duty cycle
| Frequency | Duty | Pulse-width error |
|---|---|---|
| 1kHz | 50.00% | below resolution  |
| 10kHz | 50.00% | below resolution  |
| 100kHz | 50.00% | below resolution  |
| 300kHz | 49.90% | -3.3ns |
| 500kHz | 50.60% | +12ns |
| 700kHz | 50.78% | +11ns |
| 1MHz | 50.35% | +3.5ns |
| 2MHz | 50.29% | +1.5ns |

Converted to time, the error is non-monotonic and never exceeds ~12ns, which is at or
below the scope's 10ns division. No systematic duty error is resolvable with the
present equipment.

---

## Still to characterise
- True filter corner: sweep 1.2 / 1.5 / 2MHz in low-current mode, where the filter is
  linear, and find the actual -3dB point.
- Jitter (limited by the scope's 10ns division).
- Low-frequency corner — sweep down to find -3dB, confirms the 1.3Hz calculation.
- Firmware feature validation: noise-mode SNR, AM depth.

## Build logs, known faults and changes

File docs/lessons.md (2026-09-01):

# Lessons

Mistakes made, what they cost, and the rules derived from them.

The through-line: three of the four below produced a board or a design that looked
correct and passed every check that was not a physical measurement. None of them were
design errors. Two of them cost a full PCB revision each.

## 1. The 2.21Ω incident
The BOM matcher substituted 2.21Ω for 2.21kΩ across the entire R-2R ladder.
Cost: one full respin (v1.0 boards arrived, failure discovered on delivery).

Rules:
- Before paying, read the matched part DESCRIPTION of every BOM line. Value AND unit.
- Part numbers live at the library level (`lambros25`), not assigned per-order —
  the library prevents the error class, the review-page read catches the rest.

## 2. Name/number drift
A library entry was named as a 0.1% thin-film (ERA6A) but carried the LCSC number
of a 1% thick-film part. Harmless in that position (feeding a ±20% pot), but the
same drift in a precision position would silently break the design.

Rules:
- Library name, description, and LCSC number must agree.
- Audit periodically via Parameter Manager grid — inconsistencies are visible in a
  column view that are invisible one component at a time.
- After any order-time substitution, copy the final chosen number back into the
  library the same day.

## 3. Migration errors
While migrating from KiCad into Altium, the two inputs of an LM318 were merged onto a
single net by a copy-paste that carried no visible sign of the merge. ERC passed.
Cost: one full respin (v1.1 unusable).

Rules:
- After any cross-EDA paste or import, run ERC AND a cold continuity check between the
  input pins of every op-amp instance — not just the one you were working on. The paste
  replicates; the fault can appear in stages you never touched.
- A schematic that compiles clean is not a schematic that is correct.

## 4. Max current rating
While picking components for the Butterworth filter, I selected the inductors on
inductance, package, tolerance and SRF, and did not check current rating. The parts are
rated 3mA. Actual peak current through L1 at full scale is ~15mA — five times over.

The saturating ferrite loses permeability and gains core loss, which shows up as
passband insertion loss well below the corner: -3.1dB at 1MHz where a Butterworth
should be flat. Confirmed by scaling the DAC lookup table by 4 in firmware, which
removed the entire droop with no hardware change.

Rules:
- For series elements in a low-impedance signal path, compute the actual current and
  check it against the rated/saturation current before selecting. A 60Ω system turns
  volts into real milliamps; in a filter you think in volts and hertz, not amps, which
  is exactly why the check has to be explicit.
- Simulation will never catch this. LTspice inductors are ideal and current-independent.

Hotfix / fix:
- Software: the low-current mode (lookup table /4) restores linearity at the cost of
  amplitude and two bits of resolution. Diagnostic-grade, not a fix.
- Hardware: same 10µH in 0805 or 1206 with an adequate saturation current. Costs board
  area, not money. 0603 two-terminal parts can be swapped with a soldering iron — flood
  both ends with leaded solder, alternate between pads, lift with tweezers. Price a
  named candidate on LCSC so the write-up can say what the right part would have been.

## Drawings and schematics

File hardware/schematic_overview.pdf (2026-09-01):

## PICO & R-2R LADDER

# GND 1 2

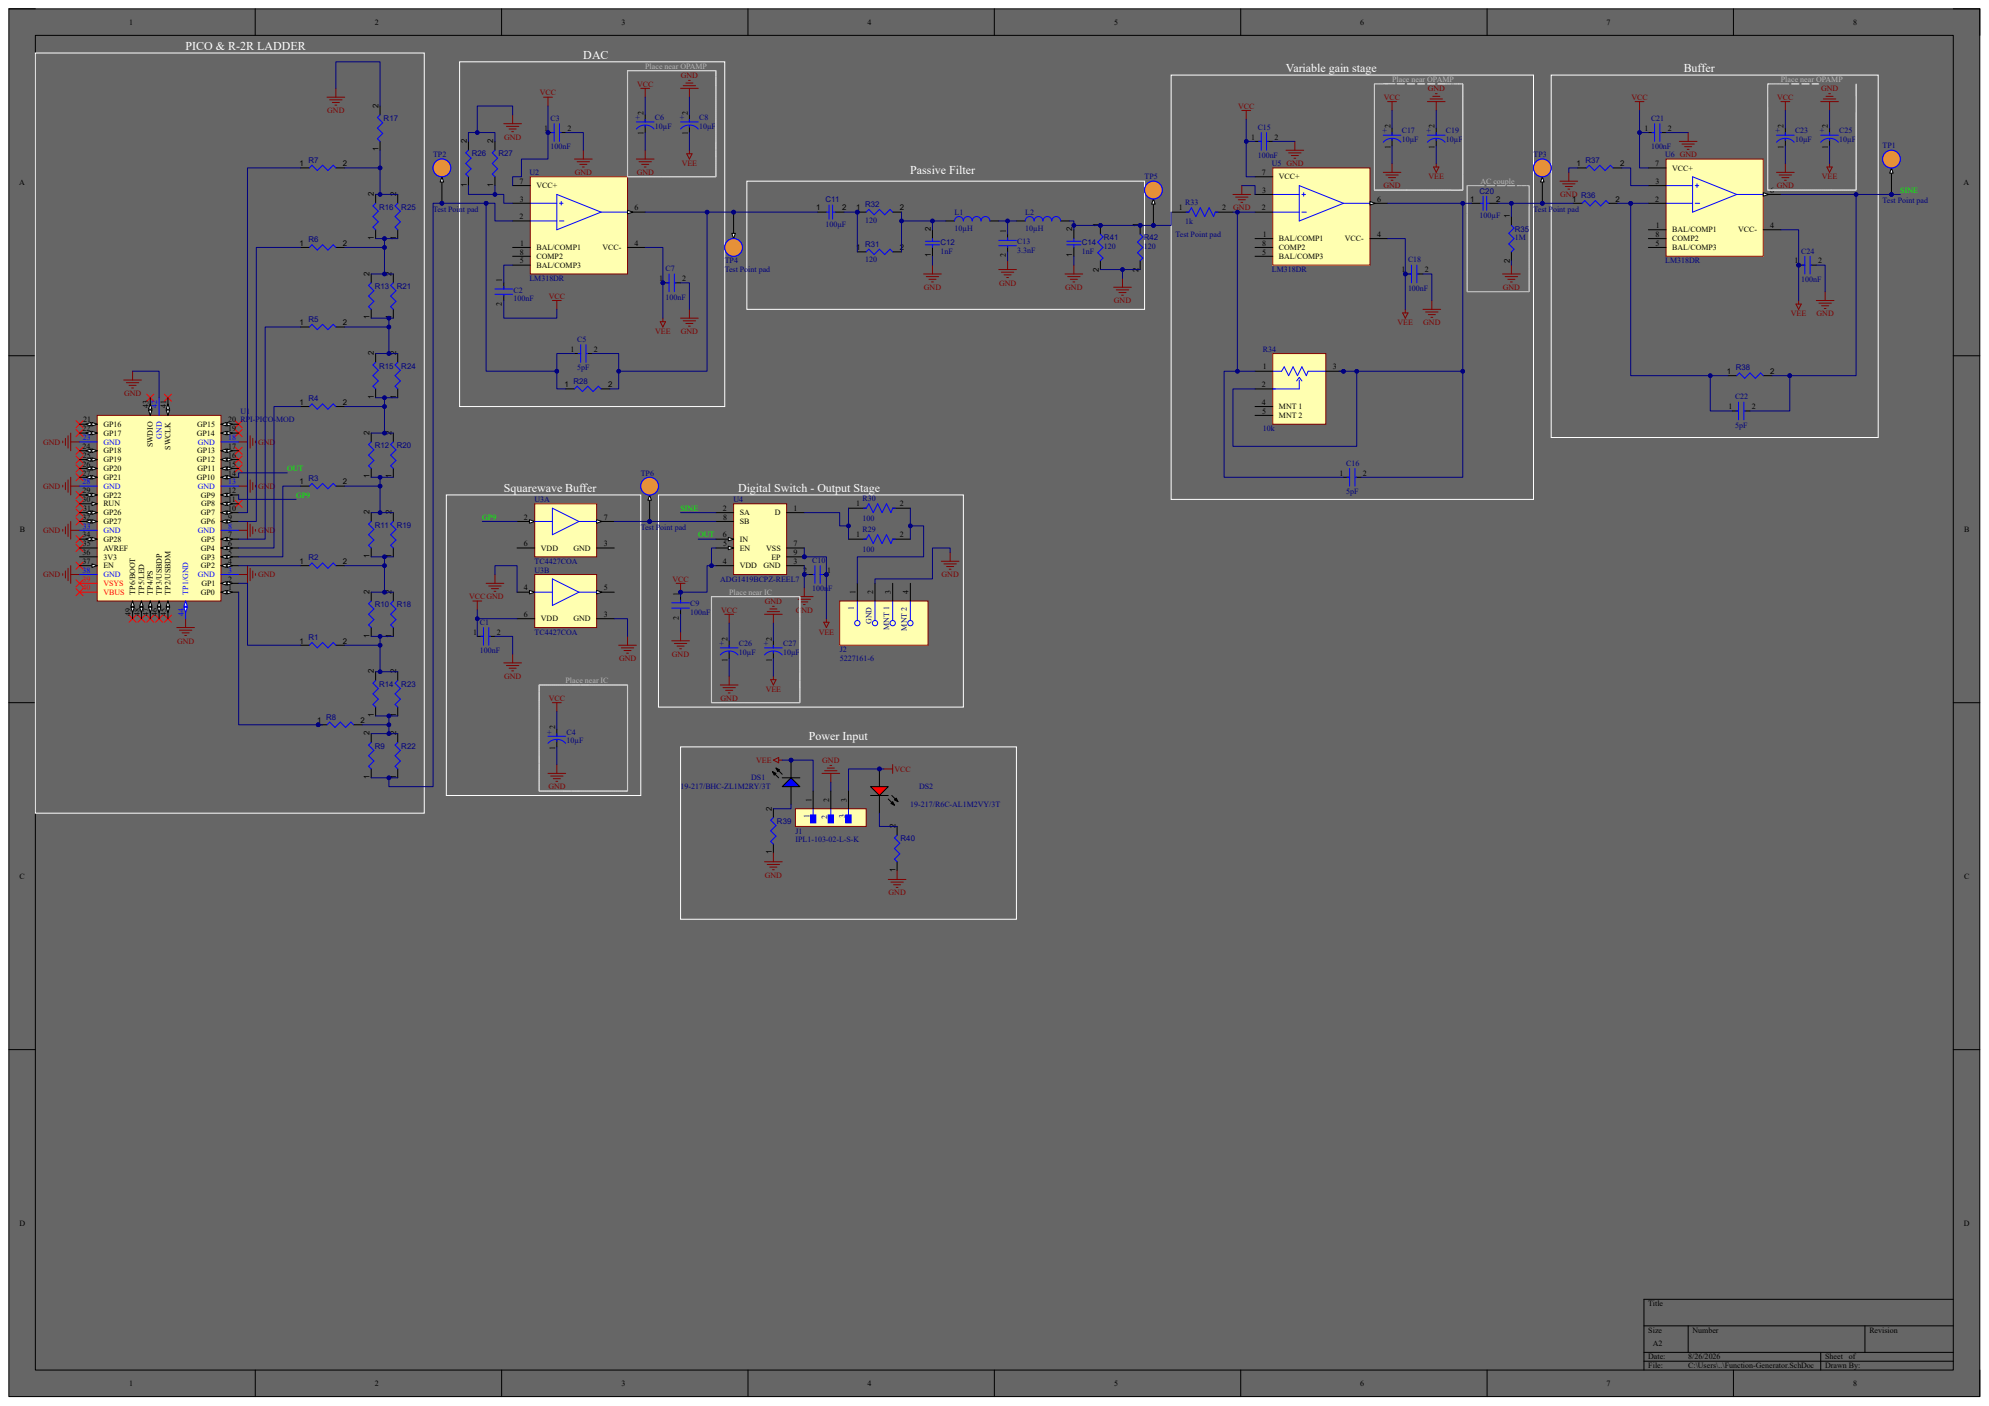
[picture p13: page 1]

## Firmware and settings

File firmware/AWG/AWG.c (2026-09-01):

#include <stdio.h>
#include <math.h> 
#include "pico/stdlib.h"
#include "pico/multicore.h"
#include "hardware/pio.h"
#include "hardware/clocks.h"
#include "hardware/vreg.h"
#include <stdlib.h>
#include <string.h>

// ===== CONFIGURATION =====
volatile float calibration_factor = 1.0f;
#define SINE_TABLE_SIZE 256
#define SAMPLE_RATE_HZ 4034843
#define DAC_PINS_BASE 0
#define SQUARE_OUT_PIN 9
// ADG1419 analog switch select. Set ADG_SQUARE_LEVEL to the logic level that
// routes the SQUARE path to the output (0 or 1 depending on wiring).
#define ADG_SELECT_PIN 10
#define ADG_SQUARE_LEVEL 1
#define OVERCLOCK_MHZ 225

// Full-scale sine amplitude keeps the R-2R ladder's inductor current under the
// 3mA design limit (docs/measurements.md). LOW mode further scales every sine
// table (SINE/NOISE/AM/FM all share these tables) to 1/4 amplitude - a
// user-toggleable, low-current mode ("<3mA" in the host UI), not just a fixed
// headroom margin. Runtime, not compile-time, so the UI can flip it live.
#define SINE_AMPLITUDE_SCALE_NORMAL 1.0f
#define SINE_AMPLITUDE_SCALE_LOW 0.25f
volatile float sine_amplitude_scale = SINE_AMPLITUDE_SCALE_NORMAL;
volatile bool low_amplitude_mode = false;
volatile bool amplitude_mode_changed = false;

// Ladder bit depth N is derived from the number of GPIO pins in the sine output
// path: DAC_PINS_BASE..DAC_PINS_BASE+7 = 8 pins drive the R-2R ladder. Full scale
// is 0..2^N-1, midscale is 2^(N-1).
#define DAC_BITS 8
#define DAC_FULL_SCALE ((1 << DAC_BITS) - 1)
#define DAC_MIDSCALE   (1 << (DAC_BITS - 1))

// Number of precomputed Gaussian noise samples. The runtime index is the top
// 16 bits of the xorshift32 output, so the noise sequence does not repeat until
// the LFSR rolls over (~2^32-1 samples).
#define NOISE_TABLE_SIZE 65536

// ===== WAVEFORM TYPES =====
typedef enum
{
    WAVEFORM_SINE,
    WAVEFORM_SQUARE,
    WAVEFORM_NOISE,
    WAVEFORM_AM,
    WAVEFORM_FM
} waveform_type_t;

// ===== GLOBALS =====
uint8_t sine_table[SINE_TABLE_SIZE];
int8_t raw_sine_table[SINE_TABLE_SIZE];
volatile uint32_t frequency_hz = 1000;
volatile bool frequency_changed = false;
volatile waveform_type_t current_waveform = WAVEFORM_SINE;
volatile bool waveform_changed = false;

// Modulation (AM/FM): carrier frequency is the existing "frequency_hz".
//  - mod_freq_hz: modulation oscillator frequency.
//  - mod_amount:  AM -> depth in percent (0..100); FM -> deviation in Hz.
volatile uint32_t mod_freq_hz = 1000;
volatile float mod_amount = 50.0f;
volatile bool mod_changed = false;

// SNR is 20*log10(V_signal_rms / V_noise_rms), measured over the full output
// bandwidth (DC to the reconstruction-filter corner ~1.5 MHz). SNR without a
// stated bandwidth is meaningless.
volatile float snr_db = 20.0f;
volatile bool snr_changed = false;

// NOISE-mode tables, owned exclusively by core 1:
//  - noise_sine_table[i] = round(A * sin(2*pi*i/256)), the sine component scaled
//    to peak amplitude A (codes). A is derived from the requested SNR.
//  - gauss_table[] holds unit-sigma Gaussian samples (std ~256 in fixed point)
//    built once from the xorshift32 LFSR via Irwin-Hall(12).
//  - noise_s_q = s * 256, the fixed-point scale that turns a unit-sigma draw
//    into a draw with sigma s (codes).
int8_t noise_sine_table[SINE_TABLE_SIZE];
int16_t gauss_table[NOISE_TABLE_SIZE];
int32_t noise_s_q = 0;

// ===== PIO PROGRAM FOR DAC (SINE) =====
const uint16_t dac_program_instructions[] = {
    0x6008, // out pins, 8
};

const struct pio_program dac_program = {
    .instructions = dac_program_instructions,
    .length = 1,
    .origin = -1,
};

// ===== PIO PROGRAM FOR SQUARE WAVE (asymmetric, autonomous) =====
// One program covers the whole frequency range and supports independent
// HIGH/LOW timing (needed for the duty-cycle correction below). The two
// half-period counts are pulled ONCE, at configure time, into the persistent
// ISR (high count) and Y (low count) registers; the wrap loop below then reads
// from those on every cycle with zero further FIFO/CPU involvement. That is
// the key property this program needs: the old CPU-fed counter method (one
// pio_sm_put_blocking per half-period) had core1's loop/scheduling jitter
// riding on every edge, which is fine at low frequency but would swamp the
// ~27ns correction this program exists to make. Running the SM undivided
// (clkdiv = 1.0) also gives single-sys-clock-cycle timing resolution.
//
// .wrap_target is the loop body; the two "pull"/"mov ..., osr" pairs above it
// are a one-time prologue that only runs once per pio_sm_init (program start).
//
//     pull   block         ; prologue: consumes the HIGH count word
//     mov    isr, osr       ;   stash it in ISR (persistent for the SM's life)
//     pull   block         ; prologue: consumes the LOW count word
//     mov    y, osr        ;   stash it in Y (persistent for the SM's life)
// .wrap_target
//     mov    x, isr        ; reload working counter = HIGH count
//     set    pins, 1
// high:
//     jmp    x--, high
//     mov    x, y          ; reload working counter = LOW count
//     set    pins, 0
// low:
//     jmp    x--, low
// .wrap
//
// HIGH duration = (high_count + 3) SM cycles, LOW duration = (low_count + 3)
// SM cycles (the "+3" is the fixed set/jmp/mov overhead each phase pays - see
// compute_square_counts()). Local instruction addresses (0-indexed within
// this program): 0=pull,1=mov isr,osr,2=pull,3=mov y,osr,4=mov x,isr (wrap
// target),5=set 1,6=jmp x--,7=mov x,y,8=set 0,9=jmp x-- (wrap).
#define SQUARE_ASYM_WRAP_TARGET 4
#define SQUARE_ASYM_WRAP 9

const uint16_t square_asym_instructions[] = {
    0x80a0, // pull   block
    0xa0c7, // mov    isr, osr
    0x80a0, // pull   block
    0xa047, // mov    y, osr
    0xa026, // mov    x, isr      (wrap_target)
    0xe001, // set    pins, 1
    0x0046, // jmp    x--, 6      (high:)
    0xa022, // mov    x, y
    0xe000, // set    pins, 0
    0x0049, // jmp    x--, 9      (low:) (wrap)
};

const struct pio_program square_asym_program = {
    .instructions = square_asym_instructions,
    .length = 10,
    .origin = -1,
};

// ===== HELPER FUNCTION =====
uint8_t reverse_bits(uint8_t b)
{
    b = (b & 0xF0) >> 4 | (b & 0x0F) << 4;
    b = (b & 0xCC) >> 2 | (b & 0x33) << 2;
    b = (b & 0xAA) >> 1 | (b & 0x55) << 1;
    return b;
}

// ===== WAVEFORM TABLE GENERATION =====
void generate_sine_table()
{
    for (int i = 0; i < SINE_TABLE_SIZE; i++)
    {
        float angle = (2.0f * M_PI * i) / SINE_TABLE_SIZE;
        uint8_t value = (uint8_t)(127.5f + 127.5f * sine_amplitude_scale * sinf(angle));
        sine_table[i] = reverse_bits(value);
    }
}

void generate_raw_sine_table()
{
    for (int i = 0; i < SINE_TABLE_SIZE; i++)
    {
        float angle = (2.0f * M_PI * i) / SINE_TABLE_SIZE;
        // Signed full-scale sine (approx sin*128) for AM/FM modulation math.
        raw_sine_table[i] = (int8_t)(127.0f * sine_amplitude_scale * sinf(angle));
    }
}

// ===== NOISE GENERATION (xorshift32 -> Irwin-Hall) =====
// Gaussian noise: xorshift32 LFSR -> Irwin-Hall(12), i.e. the sum of 12
// independent uniform 8-bit draws (three xorshift32 words, four bytes each).
// Each draw is uniform on [0,255]; the centred sum has std ~256. Irwin-Hall(12)
// is bounded at +/-6 sigma, so the resulting crest factor is ~6 (a true Gaussian
// has an unbounded crest factor). The 65536-entry gauss_table is generated once
// at startup and then sampled at a random index, which keeps the per-sample cost
// low (no per-sample CLT summation) while still producing a non-repeating stream.

static uint32_t xorshift_state = 0x9E3779B9u;

static uint32_t xorshift32(void)
{
    uint32_t x = xorshift_state;
    x ^= x << 13;
    x ^= x >> 17;
    x ^= x << 5;
    xorshift_state = x;
    return x;
}

static int32_t irwin_hall12(void)
{
    uint32_t a = xorshift32();
    uint32_t b = xorshift32();
    uint32_t c = xorshift32();
    int32_t sum = 0;
    sum += a & 0xFF; sum += (a >> 8) & 0xFF; sum += (a >> 16) & 0xFF; sum += a >> 24;
    sum += b & 0xFF; sum += (b >> 8) & 0xFF; sum += (b >> 16) & 0xFF; sum += b >> 24;
    sum += c & 0xFF; sum += (c >> 8) & 0xFF; sum += (c >> 16) & 0xFF; sum += c >> 24;
    return sum - 1530;
}

void generate_gauss_table()
{
    for (int i = 0; i < NOISE_TABLE_SIZE; i++)
    {
        gauss_table[i] = (int16_t)irwin_hall12();
    }
}

// Derive the sine amplitude A (peak, codes) and noise sigma s (codes) from SNR.
// Amplitude budget: A/sqrt(2) = s * 10^(SNR/20), and A + 4*s must fit under
// midscale (k = 4 clips ~0.006% of samples for a Gaussian; Irwin-Hall(12) rarely
// exceeds 4 sigma either). Solving gives s = 127/(sqrt(2)*10^(SNR/20) + 4) and
// A = sqrt(2) * s * 10^(SNR/20), so A is automatically scaled down as SNR drops
// and A + 4*s = 127 always. The final summed sample is clamped to [0, 2^N-1] in
// the hot loop so it can never wrap.
void recompute_noise_params()
{
    float r = powf(10.0f, snr_db / 20.0f);
    float headroom = (float)(DAC_MIDSCALE - 1);
    float s = headroom / (sqrtf(2.0f) * r + 4.0f);
    float a = sqrtf(2.0f) * r * s;

    noise_s_q = (int32_t)(s * 256.0f + 0.5f);

    for (int i = 0; i < SINE_TABLE_SIZE; i++)
    {
        float angle = (2.0f * M_PI * i) / SINE_TABLE_SIZE;
        float v = a * sine_amplitude_scale * sinf(angle);
        noise_sine_table[i] = (int8_t)(v >= 0.0f ? (v + 0.5f) : (v - 0.5f));
    }
}

// ===== MODULATION (AM/FM) PARAMETERS =====
// Recompute the modulation phase increment and the fixed-point depth/deviation
// from mod_freq_hz / mod_amount. Called on core 1 whenever modulation changes.
volatile uint32_t mod_phase_increment = 0;
volatile int32_t am_depth_q = 0;
volatile int32_t am_carrier_q = 128;
volatile int32_t fm_dev_q = 0;

void recompute_modulation()
{
    mod_phase_increment = ((uint64_t)mod_freq_hz * 4294967296ULL) / SAMPLE_RATE_HZ;

    // AM: mod_amount is depth in percent. am_depth_q = depth * 128 (Q7), 0..128.
    // To keep the envelope peaks on full scale (never clip), the carrier is
    // scaled to 1/(1+depth): am_carrier_q = 128/(1+depth) (Q7), 64..128. At 0%
    // depth the carrier is full scale; at 100% depth it is halved so the peak
    // (1+depth) = 2x envelope still lands exactly on the rail.
    float depth = mod_amount / 100.0f;
    if (depth > 1.0f) depth = 1.0f;
    if (depth < 0.0f) depth = 0.0f;
    am_depth_q = (int32_t)(depth * 128.0f + 0.5f);
    am_carrier_q = (int32_t)(128.0f / (1.0f + depth) + 0.5f);

    // FM: mod_amount is deviation in Hz. fm_dev_q is the peak phase-increment
    // change per sample, pre-shifted right by 7 so it can multiply sin_m (which is
    // sin*128) without overflowing 32 bits.
    float dev = mod_amount;
    if (dev < 0.0f) dev = 0.0f;
    fm_dev_q = (int32_t)((dev * 4294967296.0 / SAMPLE_RATE_HZ) / 128.0);
}

// ===== SQUARE-WAVE DUTY-CYCLE CORRECTION =====
// Base term: the TC4427 gate driver ahead of the ADG1419 has asymmetric
// propagation delay (t_D1 ~= 20ns typical turn-on, t_D2 ~= 40ns typical
// turn-off), which stretches every cycle's HIGH time by a fixed ~27ns as
// measured at the BNC. This alone fully explains (and corrects) the error up
// to ~100kHz.
#define SQUARE_DUTY_CORRECTION_NS 27.0f

// Above ~100kHz, a flat 27ns correction alone leaves a growing residual (a
// second, smaller fixed-time asymmetry - likely the ADG1419 itself and/or PCB
// parasitics - that the single-TC4427-constant model doesn't capture): a
// second BNC measurement pass with the base correction applied still showed
// 49.90%..52.60% from 300kHz to 2MHz instead of a flat 50%. Rather than
// modeling that second source, square_duty_cal_curve[] is a manually-measured
// total-correction-vs-frequency curve, fitted at the same points as
// docs/measurements.md's duty-cycle table, that replaces the flat constant
// above 100kHz. Below the lowest and above the highest point it holds flat;
// between points it's interpolated linearly in log10(frequency), since the
// points span decades. Re-measure and update this table if the analog
// front-end (driver, switch, PCB layout) changes.
typedef struct
{
    float freq_hz;
    float correction_ns; // total HIGH-time correction at this frequency (replaces SQUARE_DUTY_CORRECTION_NS, not added to it)
} duty_cal_point_t;

#define SQUARE_DUTY_CAL_POINTS 8
static const duty_cal_point_t square_duty_cal_curve[SQUARE_DUTY_CAL_POINTS] = {
    {    1000.0f, SQUARE_DUTY_CORRECTION_NS }, // 50.00% measured with the flat correction - on curve
    {   10000.0f, SQUARE_DUTY_CORRECTION_NS }, // 50.00%
    {  100000.0f, SQUARE_DUTY_CORRECTION_NS }, // 50.00%
    {  300000.0f,               23.7f       }, // 49.90% measured -> correction trimmed down ~3ns
    {  500000.0f,               39.0f       }, // 50.60% measured -> +12ns over the flat value
    {  700000.0f,               37.0f       }, // 50.70% measured -> +10ns
    { 1000000.0f,               37.0f       }, // 51.00% measured -> +10ns
    { 2000000.0f,               40.0f       }, // 52.60% measured -> +13ns
};
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
int main()
{
    // Overclock to 225MHz
    vreg_set_voltage(VREG_VOLTAGE_1_20);
    sleep_ms(10);
    set_sys_clock_khz(OVERCLOCK_MHZ * 1000, true);

    stdio_init_all();
    sleep_ms(2000);

    printf("\n=== Pico Signal Generator (Overclocked to %d MHz) ===\n", OVERCLOCK_MHZ);
    printf("Commands:\n");
    printf("  f<number> - Set frequency in Hz (e.g., f1000 for 1kHz)\n");
    printf("  c<number> - Set calibration factor (e.g., c1.06, SINE/NOISE only)\n");
    printf("  sine      - Switch to sine wave (output: pins 0-7 R-2R DAC)\n");
    printf("  square    - Switch to square wave (output: GPIO 9, PIO-generated)\n");
    printf("  noise     - Switch to sine + Gaussian noise (output: pins 0-7)\n");
    printf("  snr<db>   - Set noise SNR in dB, 0.0-60.0 (e.g., snr20)\n");
    printf("  am        - Switch to amplitude modulation (carrier = f)\n");
    printf("  fm        - Switch to frequency modulation (carrier = f)\n");
    printf("  m<number> - Set modulation frequency in Hz (AM/FM)\n");
    printf("  d<number> - Set modulation: AM depth %% (0-100), FM deviation Hz\n");
    printf("  duty<pct> - Set square duty cycle %% (1-99, e.g. duty30)\n");
    printf("  corr<0/1> - Enable/disable TC4427 duty-cycle correction (SQUARE only)\n");
    printf("  amp<0/1>  - Low-current (<3mA) 1/4-amplitude mode, SINE/NOISE/AM/FM\n");
    printf("  i         - Show current info\n\n");

    generate_sine_table();
    generate_raw_sine_table();

    multicore_launch_core1(core1_entry);

    printf("Generator running at %d Hz\n", frequency_hz);
    printf("Waveform: SINE\n");
    printf("SNR: %.1f dB\n", snr_db);
    printf("Calibration factor: %.4f (applies to SINE/NOISE only)\n", calibration_factor);

    char input_buffer[64];
    int buffer_pos = 0;

    while (true)
    {
        int c = getchar_timeout_us(0);

        if (c != PICO_ERROR_TIMEOUT)
        {
            if (c == '\n' || c == '\r')
            {
                input_buffer[buffer_pos] = '\0';

                if (buffer_pos > 0)
                {
                    if (strcmp(input_buffer, "sine") == 0)
                    {
                        current_waveform = WAVEFORM_SINE;
                        waveform_changed = true;
                        printf("Waveform: SINE (output on pins 0-7, calibration applied)\n");
                    }
                    else if (strcmp(input_buffer, "square") == 0)
                    {
                        current_waveform = WAVEFORM_SQUARE;
                        waveform_changed = true;
                        printf("Waveform: SQUARE (output on GPIO 9, PIO-generated, duty target %.2f%%, achieved %.2f%%, correction %s)\n",
                               square_duty_percent, square_achieved_duty_percent,
                               duty_correction_enabled ? "ON" : "OFF");
                    }
                    else if (strcmp(input_buffer, "noise") == 0)
                    {
                        current_waveform = WAVEFORM_NOISE;
                        waveform_changed = true;
                        printf("Waveform: NOISE (sine + Gaussian noise, SNR %.1f dB, output on pins 0-7)\n", snr_db);
                    }
                    else if (strcmp(input_buffer, "am") == 0)
                    {
                        current_waveform = WAVEFORM_AM;
                        waveform_changed = true;
                        printf("Waveform: AM (carrier %d Hz, mod %d Hz, depth %.1f%%)\n", frequency_hz, mod_freq_hz, mod_amount);
                    }
                    else if (strcmp(input_buffer, "fm") == 0)
                    {
                        current_waveform = WAVEFORM_FM;
                        waveform_changed = true;
                        printf("Waveform: FM (carrier %d Hz, mod %d Hz, deviation %.1f Hz)\n", frequency_hz, mod_freq_hz, mod_amount);
                    }
                    else if (input_buffer[0] == 'f')
                    {
                        uint32_t new_freq = atoi(&input_buffer[1]);
                        if (new_freq > 0 && new_freq <= 50000000)
                        {
                            frequency_hz = new_freq;
                            frequency_changed = true;
                            printf("Frequency set to %d Hz\n", new_freq);
                        }
                        else
                        {
                            printf("Invalid frequency (range: 1-50000000 Hz)\n");
                        }
                    }
                    else if (strncmp(input_buffer, "corr", 4) == 0 && strlen(input_buffer) > 4)
                    {
                        // Checked ahead of the single-'c' calibration branch below,
                        // since "corr0"/"corr1" would otherwise match it first.
                        int new_corr = atoi(&input_buffer[4]);
                        duty_correction_enabled = (new_corr != 0);
                        duty_changed = true;
                        printf("Duty-cycle correction (TC4427, SQUARE only): %s\n",
                               duty_correction_enabled ? "ON" : "OFF");
                    }
                    else if (input_buffer[0] == 'c')
                    {
                        float new_cal = atof(&input_buffer[1]);
                        if (new_cal > 0.5 && new_cal < 1.5)
                        {
                            calibration_factor = new_cal;
                            frequency_changed = true;
                            printf("Calibration factor set to %.4f (SINE/NOISE mode only)\n", new_cal);
                        }
                        else
                        {
                            printf("Invalid calibration (range: 0.5-1.5)\n");
                        }
                    }
                    else if (strncmp(input_buffer, "snr", 3) == 0 && strlen(input_buffer) > 3)
                    {
                        float new_snr = atof(&input_buffer[3]);
                        if (new_snr >= 0.0f && new_snr <= 60.0f)
                        {
                            snr_db = new_snr;
                            snr_changed = true;
                            printf("SNR set to %.1f dB\n", new_snr);
                        }
                        else
                        {
                            printf("Invalid SNR (range: 0.0-60.0 dB)\n");
                        }
                    }
                    else if (input_buffer[0] == 'm' && strlen(input_buffer) > 1)
                    {
                        uint32_t new_mod = atoi(&input_buffer[1]);
                        if (new_mod > 0 && new_mod <= 1000000)
                        {
                            mod_freq_hz = new_mod;
                            mod_changed = true;
                            printf("Modulation frequency set to %d Hz\n", new_mod);
                        }
                        else
                        {
                            printf("Invalid modulation frequency (range: 1-1000000 Hz)\n");
                        }
                    }
                    else if (strncmp(input_buffer, "duty", 4) == 0 && strlen(input_buffer) > 4)
                    {
                        // Checked ahead of the single-'d' mod-amount branch below,
                        // since "duty30" would otherwise match it first.
                        float new_duty = atof(&input_buffer[4]);
                        if (new_duty >= 1.0f && new_duty <= 99.0f)
                        {
                            square_duty_percent = new_duty;
                            duty_changed = true;
                            printf("Square duty target set to %.2f%% (SQUARE only)\n", new_duty);
                        }
                        else
                        {
                            printf("Invalid duty (range: 1.0-99.0 %%)\n");
                        }
                    }
                    else if (strncmp(input_buffer, "amp", 3) == 0 && strlen(input_buffer) > 3)
                    {
                        int new_amp = atoi(&input_buffer[3]);
                        low_amplitude_mode = (new_amp != 0);
                        amplitude_mode_changed = true;
                        printf("Amplitude mode (SINE/NOISE/AM/FM): %s\n",
                               low_amplitude_mode ? "LOW (<3mA, 1/4 scale)" : "NORMAL");
                    }
                    else if (input_buffer[0] == 'd' && strlen(input_buffer) > 1)
                    {
                        float new_amount = atof(&input_buffer[1]);
                        if (new_amount >= 0.0f && new_amount <= 100000.0f)
                        {
                            mod_amount = new_amount;
                            mod_changed = true;
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

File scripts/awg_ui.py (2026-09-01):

#!/usr/bin/env python3
"""AWG Function Generator — desktop UI.

A dark, minimalist Tkinter UI (portfolio aesthetic) that talks to the Pico
firmware over USB CDC serial using the same plain-text protocol:
    f<Hz>, c<cal>, sine/square/noise/am/fm, snr<dB>, m<Hz>, d<amount>,
    duty<pct>, corr<0/1>, amp<0/1>, i

Requires pyserial:  pip install pyserial
"""

import math
import queue
import random
import threading
import tkinter as tk
from tkinter import messagebox

try:
    import serial
    from serial.tools import list_ports
except ImportError:
    _root = tk.Tk()
    _root.withdraw()
    messagebox.showerror(
        "AWG — dependency missing",
        "pyserial is not installed.\n\nInstall it with:\n"
        "    py -3.13 -m pip install pyserial",
    )
    _root.destroy()
    raise SystemExit(1)

# ---------------------------------------------------------------------------
# Device constants (mirror firmware/AWG.c)
# ---------------------------------------------------------------------------
SAMPLE_RATE_HZ = 4034843
DAC_BITS = 8
DAC_FULL = (1 << DAC_BITS) - 1      # 255
DAC_MID = 1 << (DAC_BITS - 1)       # 128
HEADROOM = DAC_MID - 1              # 127  (2^(N-1) - 1)
BAUD = 115200

# ---------------------------------------------------------------------------
# Palette — dark, near-black, cream text, mint accent
# ---------------------------------------------------------------------------
BG          = "#0a0a0a"
BG_DEEP     = "#060606"
PANEL       = "#111111"
PANEL_2     = "#181818"
BORDER      = "#262626"
BORDER_SOFT = "#1b1b1b"
TEXT        = "#f0efe6"
TEXT_2      = "#b9b8b0"
MUTED       = "#8a8983"
FAINT       = "#5e5d59"
ACCENT      = "#b5ecda"
ACCENT_DIM  = "#7fb2a4"
ACCENT_BG   = "#16241f"
ACCENT_DK   = "#0a1f1a"
GRID        = "#1c1c1c"
ERR         = "#d98a80"
WARN        = "#e8a05c"
WARN_DIM    = "#7a4d26"

FONT        = ("Segoe UI", 10)
FONT_BOLD   = ("Segoe UI", 10, "bold")
FONT_SMALL  = ("Segoe UI", 9)
FONT_LABEL  = ("Segoe UI", 8, "bold")
FONT_TITLE  = ("Segoe UI", 22, "bold")
FONT_MONO   = ("Consolas", 9)


def amp_from_snr(snr_db):
    """Return (sine peak amplitude A, noise sigma s) in DAC codes for a given SNR."""
    r = 10.0 ** (snr_db / 20.0)
    s = HEADROOM / (math.sqrt(2.0) * r + 4.0)
    a = math.sqrt(2.0) * r * s
    return a, s


def clamp(v, lo, hi):
    return max(lo, min(hi, v))


def fmt_freq(v):
    if v >= 1e6:
        return f"{v / 1e6:.2f}M"
    if v >= 1e3:
        return f"{v / 1e3:.2f}k"
    return f"{v:.0f}"


HELP_TEXT = {
    "sine": (
        "Pure sine from a 256-entry phase-accumulator (DDS) table feeding the 8-bit "
        "R-2R DAC (GPIO 0-7) at 4.03 MS/s. Clean output to ~1 MHz through the "
        "5th-order Butterworth reconstruction filter (~1.5 MHz corner). "
        "The calibration factor tunes the effective sample rate to trim frequency error."
    ),
    "square": (
        "Square wave generated by a PIO state machine on GPIO 9 and buffered by a "
        "TC4427 driver. The ADG1419 switch routes the square path to the BNC, "
        "bypassing the DAC and filter, so edges stay fast."
    ),
    "noise": (
        "A sine summed with pseudorandom Gaussian noise at a user-set SNR.\n"
        "SNR = 20·log10(V_signal_rms / V_noise_rms), measured over the full output "
        "bandwidth (DC to the ~1.5 MHz filter corner).\n"
        "Noise: xorshift32 LFSR → Irwin-Hall(12), crest factor ≈ 6.\n"
        "Amplitude budget: A/√2 = s·10^(SNR/20) with A + 4s = 127 — the sine is scaled "
        "down as SNR drops, and the summed sample is clamped to 0..255.\n"
        "SNR range: 0–60 dB."
    ),
    "am": (
        "Amplitude modulation: the carrier sine (frequency f) has its amplitude varied "
        "by a sine at the modulation frequency. Depth (0–100%) controls how much.\n"
        "Output = carrier · (1 + depth · sin(2π f_m t)).\n"
        "The carrier is scaled to 1/(1+depth) so the envelope peaks always land on "
        "full scale and never clip — 0% depth is a full-scale carrier, 100% depth "
        "halves the carrier so the 2× envelope still fits within the DAC range."
    ),
    "fm": (
        "Frequency modulation: the carrier sine's instantaneous frequency is deviated "
        "by a sine at the modulation frequency.\n"
        "Output = sin(2π f_c t + β·sin(2π f_m t)), β = deviation / f_m.\n"
        "Deviation is in Hz."
    ),
}


class PillButton(tk.Canvas):
    """A rounded, flat button drawn on a Canvas (pill shape)."""

    def __init__(self, master, text, command, width=116, height=38,
                 kind="ghost", selectable=False):
        super().__init__(master, width=width, height=height, bg=BG,
                         highlightthickness=0, bd=0, cursor="hand2")
        self.text = text
        self.command = command
        self.kind = kind
        self.selectable = selectable
        self.selected = False
        self._hover = False
        self._pw = width
        self._ph = height
        self.bind("<Enter>", lambda e: self._set_hover(True))
        self.bind("<Leave>", lambda e: self._set_hover(False))
        self.bind("<Button-1>", self._on_click)
        self._draw()

    def _set_hover(self, on):
        self._hover = on
        self._draw()

    def set_selected(self, selected):
        self.selected = selected
        self._draw()

    def _on_click(self, _event=None):
        if self.command:
            self.command()

    def _draw(self):
        self.delete("all")
        w, h = self._pw, self._ph
        r = h / 2
        fill, outline, fg = BG, BORDER, TEXT_2
        if self.kind == "accent":
            fill = "#c9f6e9" if self._hover else ACCENT
            outline = ACCENT
            fg = ACCENT_DK
        elif self.selectable and self.selected:
            fill = ACCENT_BG
            outline = ACCENT_DIM
            fg = ACCENT
        elif self._hover:
            outline = "#4b4b45"
            fg = TEXT
        self._round_rect(1, 1, w - 1, h - 1, r, fill=fill, outline=outline, width=1)
        self.create_text(w / 2, h / 2, text=self.text, fill=fg, font=FONT_BOLD)

    def _round_rect(self, x1, y1, x2, y2, r, **kw):
        pts = [x1 + r, y1, x2 - r, y1, x2, y1, x2, y1 + r,
               x2, y2 - r, x2, y2, x2 - r, y2, x1 + r, y2,
               x1, y2, x1, y2 - r, x1, y1 + r, x1, y1]
        return self.create_polygon(pts, smooth=True, **kw)
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

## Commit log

2026-01-15 Build for pico, led pulsate code and updated englog names. Also entered new log
2026-02-24 Added coupling capacitors, removed dc bias, added simple amplitute control and schematics. As always more info in \logs"
    [AWGGF -- Sinewave.kicad_pcb, AWGGF -- Sinewave.kicad_sch]
2026-02-26 lm318 arrived. Installed yet new issues arise. Check the latest EngLog
    [AWGGF -- Sinewave.kicad_sch]
2026-02-27 First major success
    [AWGGF -- Sinewave.kicad_sch]
2026-02-28 Updated docs and short term goals. As well as miscellaneous changes
    [AWG.c]
2026-03-01 Added schematic image
2026-03-01 Schematic img right extension
2026-03-01 reordering folders
    [AWGGF -- Sinewave.kicad_pcb, AWGGF -- Sinewave.kicad_sch]
2026-03-03 Transistor experiments
    [AWGGF -- Sinewave.kicad_pcb, AWGGF -- Sinewave.kicad_sch]
2026-03-13 First square working prototype
2026-03-25 First proper 1MHz output. Check EngLog for details
    [AWGGF -- Sinewave.kicad_sch]
2026-03-26 Found small issue, fixed cduty cycle variance. Check englog
    [AWG.c]
2026-06-30 added altium files
    [AWGGF -- Sinewave.kicad_pcb, AWGGF -- Sinewave.kicad_sch, Function Generator.PrjPcb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]
2026-07-06 logs and documentation
    [logo.dxf]
2026-07-18 V1.1 Butterscotch filter added. Errors with BOM fixed
    [Function Generator.PrjPcb, Function-Generator.PcbDoc, Function-Generator.SchDoc]
2026-08-31 Created UI Created noise mode Created AM, FM mode
    [Function Generator working.PrjPcb]
2026-09-01 Firmware: square duty-cycle correction, low-current mode, docs audit; add engineering process report
    Firmware (AWG.c):
    - Replace the toggle/counter square-wave PIO split with one autonomous
    asymmetric-duty program, giving single-cycle timing resolution and
    duty support at any frequency.
    - Add TC4427 duty-cycle correction: a base 27ns constant plus a
    measured correction-vs-frequency curve above 100kHz, with a runtime
    on/off switch (corr0/corr1) and a duty<pct> command.
    - Convert the inductor-saturation low-current mode from a compile-time
    hack to a runtime-toggleable feature (amp0/amp1), exposed as a
    "<3mA" button in the host UI.
    Docs:
    - Rewrite docs/firmware.md against the firmw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
    [AWG.c, awg_ui.py]
2026-09-01 Fix supply wording and report links; move schematic into hardware/
    - README/report: supply is USB AND 2x9V batteries, not USB or batteries.
    - Move hardware/altium-exported schematic PDF from images/ into
    hardware/ (top level) so it's easy to find on GitHub, phone included.
    - Fix the report's schematic and awg_ui.py links: \repofile used the
    same string for both the URL and the escaped display text, so any
    underscored filename put a literal backslash into the href target
    and broke the link. Replaced with explicit \href calls, and pointed
    the schematic link at its new hardware/ location as a real GitHub
    URL instead of a relative path that only resolves next to the PDF.
